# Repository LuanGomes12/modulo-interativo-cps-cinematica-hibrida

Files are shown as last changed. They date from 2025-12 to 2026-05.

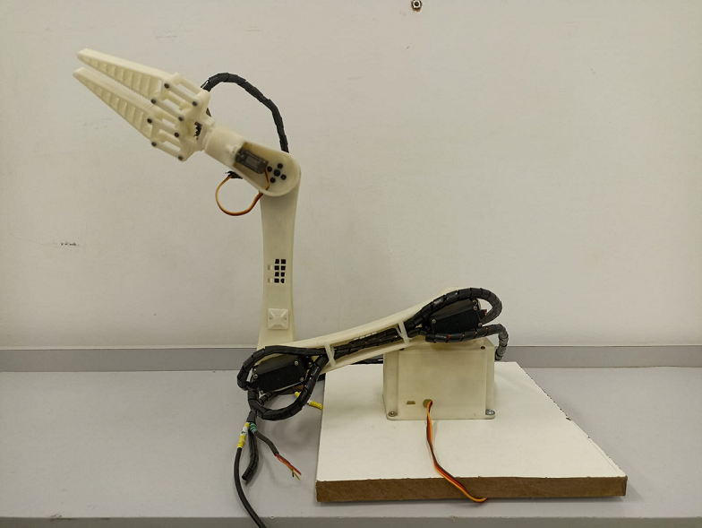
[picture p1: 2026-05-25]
modelo_simulink/Imagens/braco_real.png

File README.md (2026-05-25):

# Integração de um Modelo Digital Baseado em Cinemática Híbrida e Aprendizado de Máquina em um Manipulador Robótico Didático de 5 Juntas Rotativas


[]()

Este repositório contém o código-fonte, os modelos 3D e o *firmware* referentes ao desenvolvimento de um sistema ciber-físico interativo para controle, visualização e telemetria de um manipulador robótico didático. 

Este trabalho foi desenvolvido para a dissertação de mestrado do **Programa de Pós-Graduação em Engenharia Elétrica e de Computação (PPGEEC)** da Universidade Federal do Ceará (UFC), campus Sobral.

O objetivo principal é fornecer uma plataforma educacional e experimental (**Manipula.EDU**) que una simulação, controle, visualização e execução física em um único sistema modular, solucionando a subdeterminação da Cinemática Inversa por meio de Redes Neurais.

---

## 🚀 O Projeto Integra:

- **Modelo Mecânico CAD:** Desenvolvido e montado no Autodesk Inventor.
- **Modelo Digital (Simulação Dinâmica):** Construído no Simscape Multibody.
- **Interface Gráfica Interativa:** Desenvolvida em MATLAB (App Designer).
- **Inteligência Artificial:** Resolução da Cinemática Inversa Híbrida utilizando o modelo Perceptron de Múltiplas Camadas (MLP).
- **Comunicação Sem Fio:** Protocolo TCP/IP assíncrono entre o PC (*Host*) e o microcontrolador ESP32 (*Edge Device*).
- **Atuação Física:** Controle multiplexado de servomotores MG995 e MG90S.

---

## 📐 Arquitetura Geral do Sistema

Arquitetura_Metodologia

A comunicação ocorre via rede local sem fio (WLAN) estabelecida pelo próprio ESP32 em modo *Access Point* (AP), garantindo baixa latência e sincronização contínua entre o hardware de acrílico e o modelo virtual no Simulink.

---

## 📁 Estrutura do Repositório

```
├── /cad_inventor/       # Peças 3D, montagem completa e exportações do Simscape Multibody Link
├── /modelo_simulink/    # Modelo Simscape Multibody do manipulador e arquivos .mlapp (Interface)
├── /esp32_firmware/     # Código C++ do ESP32 (Servidor TCP, Parsing de bytes e Controle PWM)
└── README.md
```

---

## 💻 Requisitos de Software e Hardware

### MATLAB (Host)
- Versão: R2021a ou superior  
- Toolboxes necessárias:
  - Simulink  
  - Simscape  
  - Simscape Multibody  
  - Instrument Control Toolbox (para TCP/IP)  

### Autodesk Inventor
- Versão: 2022  
- Plugin **Simscape Multibody Link** instalado e configurado

**OBS:** o plugin deve ser na mesma versão do MATLAB!!!  

### ESP32
- Ambiente: PlatformIO ou Arduino IDE  
- Bibliotecas utilizadas:
  - WiFi  
  - ESP32Servo

---

## 📡 Protocolo de Comunicação TCP/IP

Para garantir desempenho e evitar overhead na rede educacional, a comunicação não utiliza strings ou JSON. O Simulink empacota as variáveis em ponto flutuante e transmite um payload bruto (vetor de bytes).

- Estrutura do Pacote de Envio (26 Bytes - MATLAB → ESP32):
  - [1 byte] Cabeçalho de sincronização (0xAA).
  - [25 bytes] 5 blocos correspondentes às 5 juntas, onde cada bloco contém:
    - [1 byte] ASCII ID da junta (ex: 'A', 'B').
    - [4 bytes] Valor angular em float (single IEEE 754).

O ESP32 recebe o pacote e utiliza uma estrutura de dados union em C++ para remontar os bytes diretamente na memória e aplicar o sinal aos servomotores, respeitando as restrições físicas (travas lógicas) da estrutura de acrílico.

## 📊 Status do Projeto

| Módulo | Status |
|---|---|
| Modelo CAD (Inventor) | ✅ Concluído |
| Exportação SMBL | ✅ Concluído |
| Modelo Digital (Simscape) | ✅ Concluído |
| App Designer (Manipula.EDU) | ✅ Concluído |
| IA (Predição de Pitch via MLP) | ✅ Concluído |
| Comunicação TCP MATLAB ↔ ESP32 | ✅ Testada/Operacional |
| Execução Física (Sincronismo) | ✅ Operacional |
| Implementação de Sensores (Malha Fechada)  | ⏳ Trabalhos Futuros |

## 👤 Autor

- Luan Gomes Magalhães Lima

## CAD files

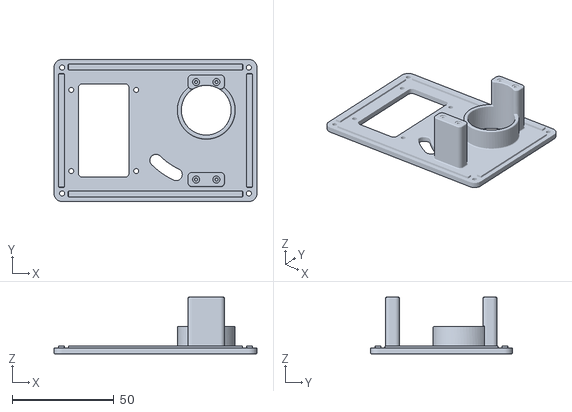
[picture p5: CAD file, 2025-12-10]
cad/inventor/peças 3D/BRAÇO ROBÓTICO R2 - Base B1 Tampa.stl
100.0 x 70.0 x 28.0

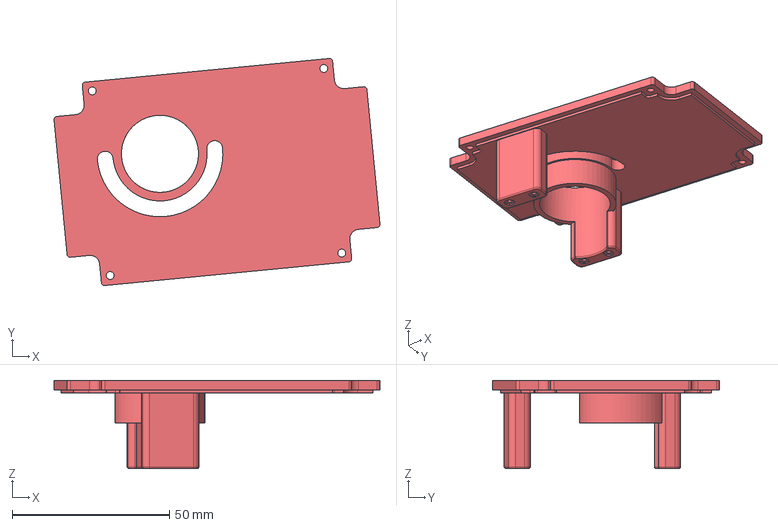
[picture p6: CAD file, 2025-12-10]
modelo_simulink/Geometria/BRAÇO ROBÓTICO - Base A2_ipt_d4445b69.STEP
103.7 x 72.2 x 28.0 mm

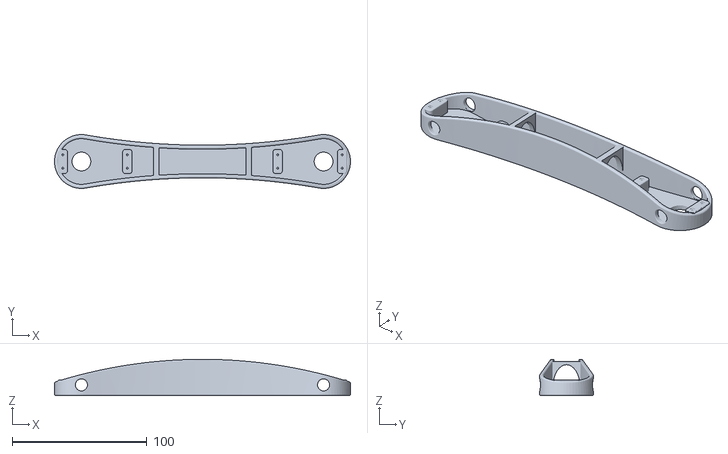
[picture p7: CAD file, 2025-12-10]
cad/inventor/peças 3D/BRAÇO ROBÓTICO R2 - Braço A.stl
220.0 x 40.0 x 27.0

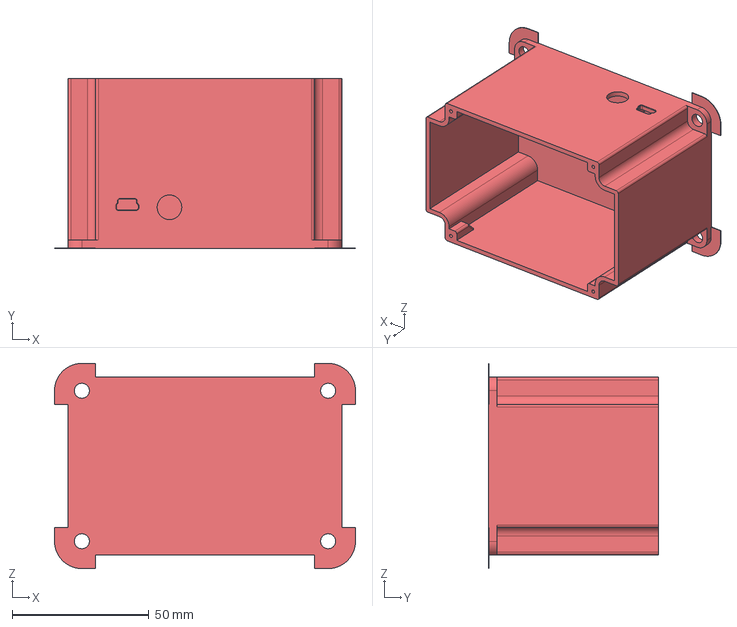
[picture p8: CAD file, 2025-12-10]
modelo_simulink/Geometria/BRAÇO ROBÓTICO - Base A1_ipt_1efede4f.STEP
110.0 x 62.0 x 75.0 mm

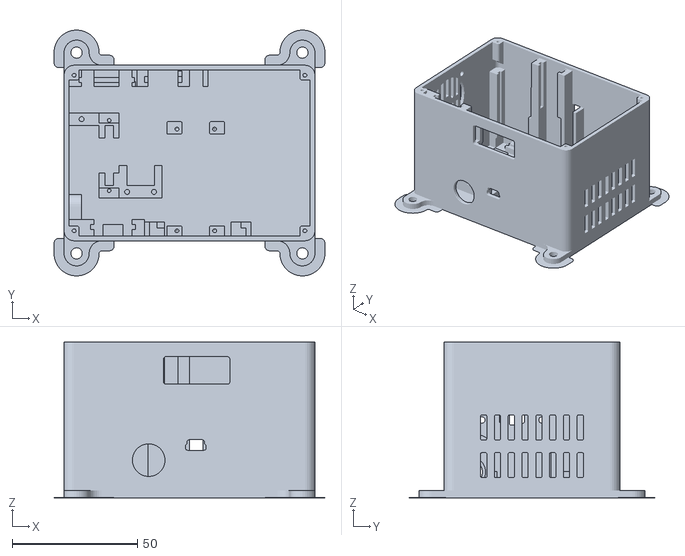
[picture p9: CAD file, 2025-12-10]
cad/inventor/peças 3D/BRAÇO ROBÓTICO R2 - Base A1.stl
108.0 x 97.9 x 62.0

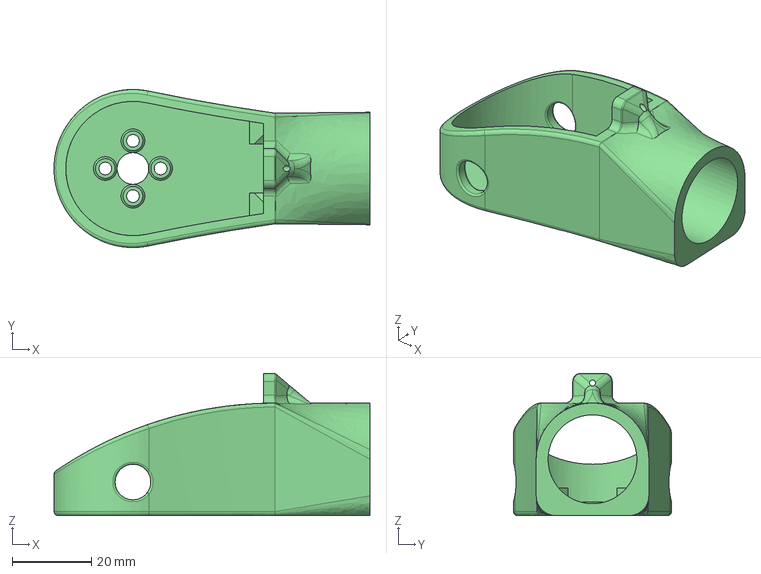
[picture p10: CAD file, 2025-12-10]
modelo_simulink/Geometria/BRAÇO ROBÓTICO - Braço C1_ipt_c91b14e4.STEP
80.0 x 40.0 x 36.0 mm

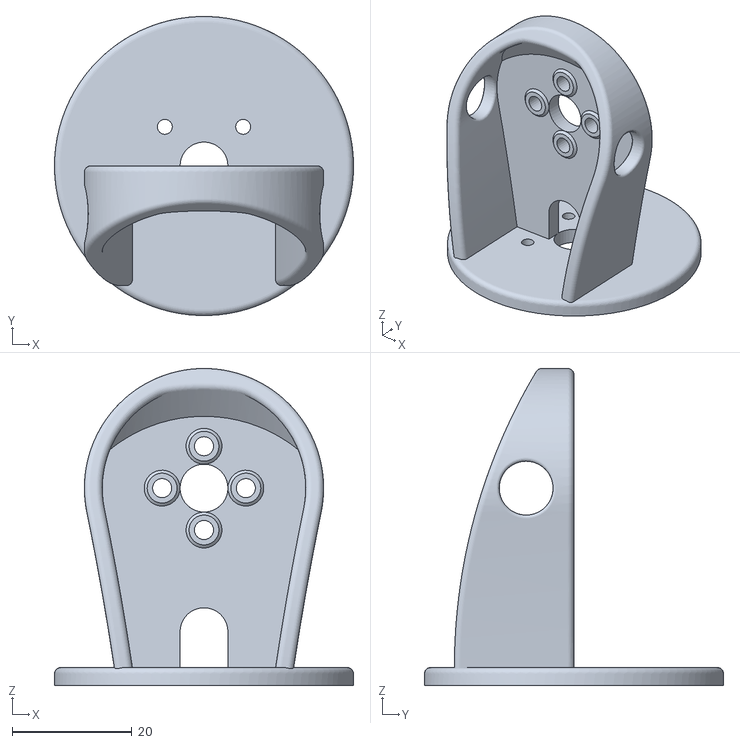
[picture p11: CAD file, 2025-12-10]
cad/inventor/peças 3D/BRAÇO ROBÓTICO R2 - Base C2.stl
50.0 x 50.0 x 53.0

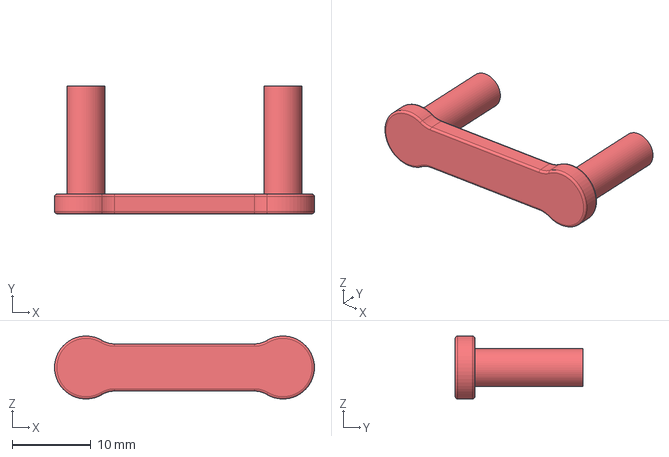
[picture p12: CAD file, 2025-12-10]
modelo_simulink/Geometria/BRAÇO ROBÓTICO - Garra A2b - Pino_ipt_ad69c09e.STEP
33.0 x 16.2 x 7.99 mm

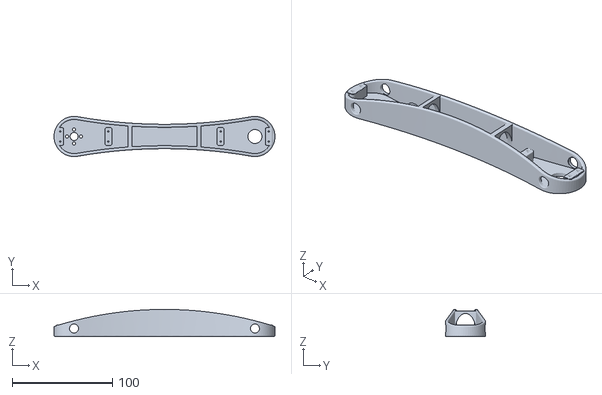
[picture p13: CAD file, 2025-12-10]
cad/inventor/peças 3D/BRAÇO ROBÓTICO R2 - Braço B.stl
220.0 x 40.0 x 27.0

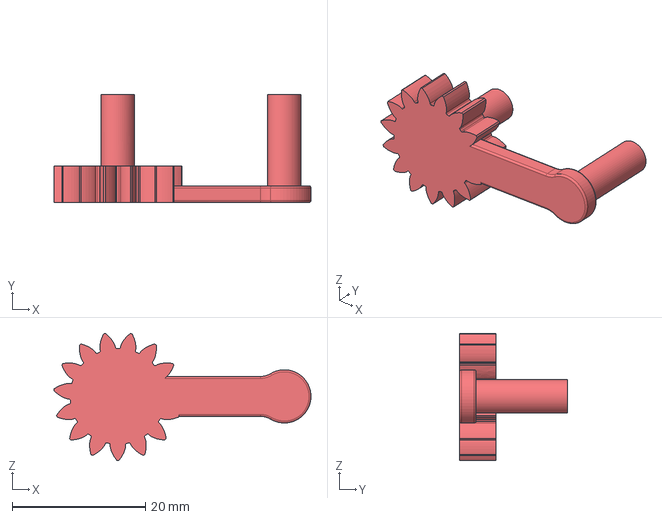
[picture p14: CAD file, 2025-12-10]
modelo_simulink/Geometria/BRAÇO ROBÓTICO - Garra A2d_ipt_ad69c09e.STEP
38.6 x 16.2 x 19.1 mm

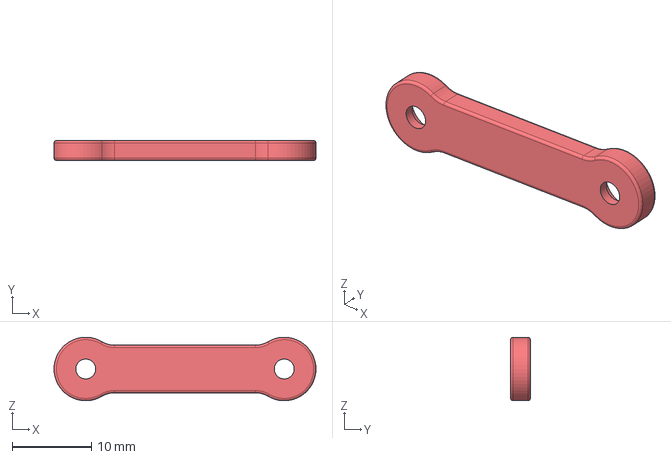
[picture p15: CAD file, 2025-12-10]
modelo_simulink/Geometria/BRAÇO ROBÓTICO - Garra A2a_ipt_ad69c09e.STEP
33.0 x 2.50 x 7.99 mm

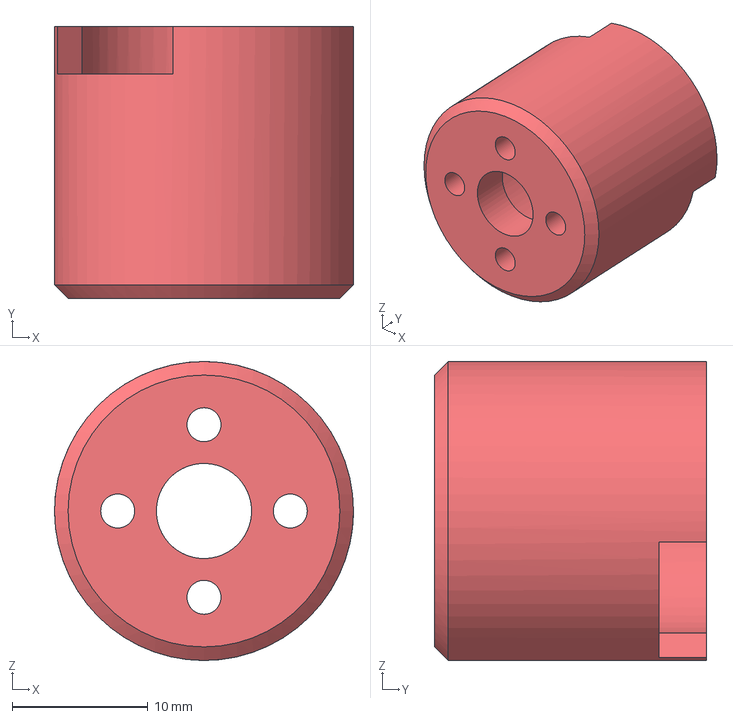
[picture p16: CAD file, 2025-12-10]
modelo_simulink/Geometria/BRAÇO ROBÓTICO - Garra A4b_ipt_9b61da0b.STEP
22.0 x 20.0 x 22.0 mm

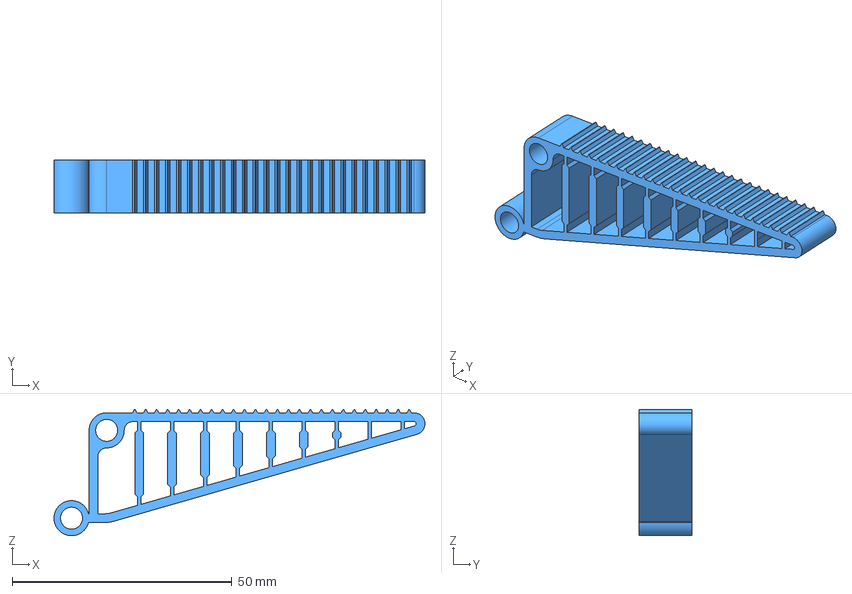
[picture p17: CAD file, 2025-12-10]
modelo_simulink/Geometria/BRAÇO ROBÓTICO - Garra A1_ipt_2e13df14.STEP
84.5 x 12.0 x 28.8 mm

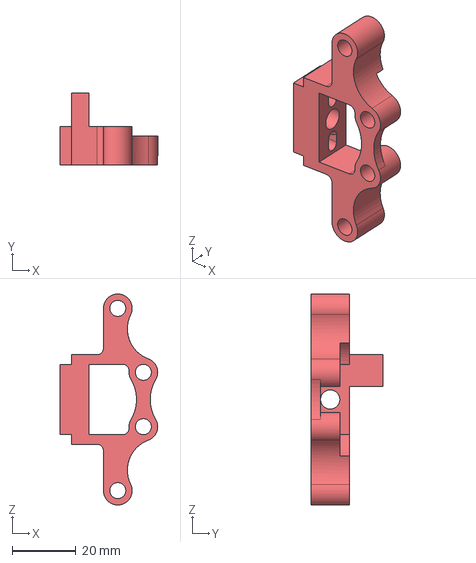
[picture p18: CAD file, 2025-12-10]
modelo_simulink/Geometria/BRAÇO ROBÓTICO - Garra A4_ipt_ac27e29f.STEP
30.5 x 22.5 x 66.0 mm

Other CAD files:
modelo_simulink/Geometria/BRAÇO ROBÓTICO - Braço B_ipt_c91b14e4.STEP
modelo_simulink/Geometria/BRAÇO ROBÓTICO - Base C2_ipt_17d74486.STEP
modelo_simulink/Geometria/BRAÇO ROBÓTICO - Braço A_ipt_c91b14e4.STEP
modelo_simulink/Geometria/BRAÇO ROBÓTICO - Garra A2c_ipt_ad69c09e.STEP
cad/inventor/modelo 3D completo/Montagem_Junta5.iam
cad/inventor/peças 3D/BRAÇO ROBÓTICO - Braço C1.ipt
cad/inventor/peças 3D/BRAÇO ROBÓTICO - Garra A1.ipt
cad/inventor/peças 3D/BRAÇO ROBÓTICO - Garra A2.ipt
cad/inventor/peças 3D/BRAÇO ROBÓTICO - Garra A2a.ipt
cad/inventor/peças 3D/BRAÇO ROBÓTICO - Garra A2b - Pino.ipt
cad/inventor/peças 3D/BRAÇO ROBÓTICO - Garra A2c.ipt
cad/inventor/peças 3D/BRAÇO ROBÓTICO - Garra A4.ipt
cad/inventor/peças 3D/BRAÇO ROBÓTICO - Garra A4b.ipt

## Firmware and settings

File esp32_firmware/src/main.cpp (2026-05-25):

#include <WiFi.h>
#include <ESP32Servo.h>

// ======= CONFIGURAÇÃO DA REDE =======
const char* ssid = [NOME_REDE];
const char* password = [SENHA_REDE];

// Porta TCP que o servidor vai escutar
WiFiServer server(5000);

// ======= CONFIGURAÇÃO DO SERVO =======
Servo servoA, servoB, servoC, servoD, servoE;
const int pinA = 13;
const int pinB = 12;
const int pinC = 14;
const int pinD = 27;
const int pinE = 26;

// Limites padrão de PWM para a maioria dos servos (ex: MG995, MG90S). 
const int minUs = 500;
const int maxUs = 2400;

// Tamanho do buffer: 26 bytes (1 Sync + 5 juntas * (1 ID + 4 bytes Float))
const int buffer_size = 26;
byte buf[buffer_size];

const byte HEADER_SYNC = 0xAA; 

union BtoF {
  byte b[4];
  float fval;
} u;

void setup() {
  Serial.begin(115200);

  // 1. ALOCAÇÃO DE TIMERS DE HARDWARE
  ESP32PWM::allocateTimer(0);
  ESP32PWM::allocateTimer(1);
  ESP32PWM::allocateTimer(2);
  ESP32PWM::allocateTimer(3);

  // 2. CONFIGURAÇÃO DE FREQUÊNCIA (50Hz)
  servoA.setPeriodHertz(50);
  servoB.setPeriodHertz(50);
  servoC.setPeriodHertz(50);
  servoD.setPeriodHertz(50);
  servoE.setPeriodHertz(50);

  // 3. ATTACH COM LIMITES DE PULSO DEFINIDOS
  servoA.attach(pinA, minUs, maxUs);
  servoB.attach(pinB, minUs, maxUs);
  servoC.attach(pinC, minUs, maxUs);
  servoD.attach(pinD, minUs, maxUs);
  servoE.attach(pinE, minUs, maxUs);

  // Configuração do Access Point
  WiFi.mode(WIFI_AP);
  WiFi.softAP(ssid, password);

  IPAddress IP = WiFi.softAPIP();
  Serial.print("Access Point criado: ");
  Serial.println(ssid);
  Serial.print("IP do ESP32: ");
  Serial.println(IP);

  server.begin();
  Serial.println("Servidor TCP iniciado na porta 5000");
}

void loop() {
  WiFiClient client = server.available();

  if (client) {
    while (client.connected()) {
      
      if (client.available() >= buffer_size) {
        client.readBytes(buf, buffer_size);

        if (buf[0] != HEADER_SYNC) {
          Serial.println("Erro de sincronização. Descartando pacote.");
          while(client.available()) client.read();
          continue; 
        }

        Serial.print("[RAW PAYLOAD]: ");
        for(int k = 0; k < buffer_size; k++) {
          if(buf[k] < 0x10) Serial.print("0"); 
          Serial.print(buf[k], HEX);
          Serial.print(" ");
        }
        Serial.println("\n[DECODIFICADO]:");

        for (int i = 0; i < 5; i++) {
          
          int offset = 1 + (i * 5); 
          char comando = (char)buf[offset];

          for (int j = 0; j < 4; j++) {
            u.b[j] = buf[offset + 1 + j];
          }
          
          float val = u.fval;
          
          // 1. Restrição Lógica: Garante que os limites do digital twin sejam respeitados
          int angulo_logico = (int)val;
          if (comando == 'E') {
            angulo_logico = constrain(angulo_logico, 0, 180);
          } else {
            angulo_logico = constrain(angulo_logico, 0, 120);
          }

          // 2. Preparação do Ângulo Físico (Motor)
          int angulo_motor = angulo_logico;

          // ======= CORREÇÃO DE REFERENCIAL FÍSICO =======
          // A Junta A está montada invertida mecanicamente.
          // O terminal mostrará o valor lógico, mas o motor receberá o valor invertido.
          if (comando == 'A') {
            angulo_motor = 120 - angulo_logico; 
          }
          // ============================================

          // 3. Acionamento do hardware com os ângulos já corrigidos e limitados
          switch (comando) {
            case 'A': servoA.write(angulo_motor); break;
            case 'B': servoB.write(angulo_motor); break;
            case 'C': servoC.write(angulo_motor); break;
            case 'D': servoD.write(angulo_motor); break;
            case 'E': servoE.write(angulo_motor); break;
            default:
              Serial.print("  Comando desconhecido: ");
              Serial.println(comando);
              break;
          }

          // 4. Impressão focada no terminal: exibe apenas o valor lógico para manter a 
          // paridade visual com os valores gerados na simulação do Simulink.
          Serial.print("  Junta ");
          Serial.print(comando);
          Serial.print(" -> Angulo: ");
          Serial.print(angulo_logico);
          
          Serial.println();
        }
        
        Serial.println("------------------------------------------------"); 
        client.println("OK"); 
      }
    }
    client.stop();
    Serial.println("Cliente desconectado");
  }
}

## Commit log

2025-12-10 Upload pastas
    [BRAÇO ROBÓTICO - Base A1_ipt_1efede4f.STEP, BRAÇO ROBÓTICO - Base A2_ipt_d4445b69.STEP, BRAÇO ROBÓTICO - Base C2_ipt_17d74486.STEP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]
2026-05-25 Upload do modelo simulink
    [BRAÇO ROBÓTICO - Base A1_ipt_1efede4f.STEP, BRAÇO ROBÓTICO - Base A2_ipt_d4445b69.STEP, BRAÇO ROBÓTICO - Base C2_ipt_17d74486.STEP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]
